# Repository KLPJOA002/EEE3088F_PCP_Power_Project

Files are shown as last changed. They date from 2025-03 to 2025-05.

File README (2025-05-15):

# Micromouse Power Subsystem – EEE3088F 2025

This repository contains the design files, documentation, and supporting material for the **Micromouse Power Subsystem** designed as part of the EEE3088F course at the University of Cape Town. The subsystem was built to meet a strict set of functional and mechanical requirements under tight budget constraints.

## 🧭 Project Overview

Micromouse is a global robotics competition in which small autonomous robots solve mazes. The UCT EEE3088F course replicates this challenge by requiring students to develop individual subsystems that together build a complete micromouse. This repository documents the design and implementation of the **Power Subsystem**, which is responsible for:

- Bidirectional control of 4 motors (2x 200mA, 2x 500mA)
- Battery charging (with selectable fast and slow charging modes)
- USB-C PD negotiation (9V)
- 5V and 3.3V regulation
- External load switching (2x 1A high-side loads)
- Ultra-low power OFF mode (<30µA)
- INA219 current and voltage monitoring

---

## 🗂 Repository Structure

---

## 🛠 Hardware Requirements

- **Battery**: 3.7V 800mAh LiPo (Micro Robotics)
- **USB PD IC**: HUSB237 for 9V negotiation
- **Motor Driver**: DRV8833 for up to 2A peak per motor
- **Load Switch**: AP22814 (3A capable, overcurrent protected)
- **Battery Monitor**: INA219 over I2C
- **Charging IC**: TP4056-42-ESOP8
- **Voltage Regulators**:
  - 5V: MT3608 Boost Converter
  - 3.3V: AMS1117-3.3 Linear Regulator

---

## ✅ Final Design Summary

- **Footprint**: 82mm × 60mm, mounted via motherboard drill holes
- **Connector**: 2×16 2.54mm header, JST-PH battery connector
- **5V and 3.3V Outputs**:
  - 5V output: up to 1.5A (±5%)
  - 3.3V output: up to 300mA (±5%)
- **Charging Modes**:
  - Slow: ~200mA (logic low on control pin)
  - Fast: ~600mA (logic high on control pin)
- **Sleep Mode**: OFF current draw <30µA, confirmed via test pads
- **INA219**: Allows shunt-based battery current measurement

---

## 🔧 How to Use

1. Open the KiCad project in `/KiCad_Files`.
2. Review schematic, footprints, and PCB constraints.
3. Upload files from `/Gerbers`, `/PnP`, and `/BOM` to JLCPCB.
4. Use `/Screenshots` for evidence of successful upload and configuration.

---

## 📦 JLCPCB Submission

All files have been validated and successfully uploaded to JLCPCB. Screenshots showing the:
- Correct **BOM upload**
- Matching **cart configuration**
are provided in `/Screenshots`.

---

## 👨‍💻 Authors

- **Alex Hillman** `HLLALE010`
- **Joab Kloppers** `KLPJOA002`
Both team members contributed distinct sections of the PCB design and documentation, as per the individual assessment requirements of the course.

- GitHub: [EEE3088F_PCP_Power_Project](https://github.com/KLPJOA002/EEE3088F_PCP_Power_Project)

> Contributions are limited to the Power Subsystem. Design files and reports are subject to UCT's academic integrity policies.

---

## 📜 License

This project is licensed for academic purposes only.

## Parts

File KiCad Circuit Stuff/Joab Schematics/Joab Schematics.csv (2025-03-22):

Source: | C:\Users\joabk\OneDrive - University of Cape Town\2025\Sem1\EEE3088F Material\MM Project\KiCad Circuit Stuff\Joab Schematics\Joab Schematics.kicad_sch
Date: | 2025/03/21 17:14:41
Tool: | Eeschema 7.0.1
Generator: | C:\Program Files\KiCad\7.0\bin\scripting\plugins/bom_csv_grouped_by_value_with_fp.py
Component Count: | 9
Ref | Qnty | Value | Cmp name | Footprint | Description | Vendor | DNP
C1, C2 | 2 | 22u | C_Small |  | Unpolarized capacitor, small symbol
D1 | 1 | SS34 | D_Schottky_Small |  | Schottky diode, small symbol
J1 | 1 | Conn_02x16_Odd_Even | Conn_02x16_Odd_Even |  | Generic connector, double row, 02x16, odd/even pin numbering scheme (row 1 odd numbers, row 2 even numbers), script generated (kicad-library-utils/schlib/autogen/connector/)
L1 | 1 | 10u | L_Small |  | Inductor, small symbol
R1 | 1 | 680k | R_Small_US |  | Resistor, small US symbol
R2 | 1 | 56k | R_Small_US |  | Resistor, small US symbol
R3 | 1 | 100k | R_Small_US |  | Resistor, small US symbol
U1 | 1 | MT3608 | MT3608 | Package_TO_SOT_SMD:SOT-23-6 | High Efficiency 1.2MHz 2A Step Up Converter, 2-24V Vin, 28V Vout, 4A current limit, 1.2MHz, SOT23-6

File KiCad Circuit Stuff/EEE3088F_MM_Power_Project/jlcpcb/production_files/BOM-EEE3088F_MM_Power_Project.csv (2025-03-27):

Comment | Designator | Footprint | LCSC | Quantity
1k | R12 | R_0402_1005Metric_Pad0.72x0.64mm_HandSolder | C11702 | 1
2.2uF | C11,C15 | C_0402_1005Metric_Pad0.74x0.62mm_HandSolder | C12530 | 2
22u | C1,C2 | C_1206_3216Metric_Pad1.33x1.80mm_HandSolder | C12891 | 2
CA45-A-10V-22UF-K | C5 | CASE-A_3216 | C129272 | 1
100p | C3 | C_0603_1608Metric_Pad1.08x0.95mm_HandSolder | C14858 | 1
10nF | C12,C16 | C_0402_1005Metric_Pad0.74x0.62mm_HandSolder | C15195 | 2
100nF | C23,C32 | C_0402_1005Metric_Pad0.74x0.62mm_HandSolder | C1525 | 2
10p | C8 | C_0603_1608Metric_Pad1.08x0.95mm_HandSolder | C1634 | 1
TP4056 | U5 | ESOP-8_L4.9-W3.9-P1.27-LS6.0-BL-EP | C16581 | 1
SS-12D06-G050 | U11 | SW-TH_3P-P4.70_SS-12D06-G050 | C17179521 | 1
220u | C10,C20,C21,C30,C31 | C_Elec_6.3x7.7 | C19100600 | 5
4.7u | C6 | C_0603_1608Metric_Pad1.08x0.95mm_HandSolder | C19666 | 1
10uF | C14,C17,C7,C9 | C_0603_1608Metric_Pad1.08x0.95mm_HandSolder | C19702 | 4
0R | R5,R6 | R_0603_1608Metric_Pad0.98x0.95mm_HandSolder | C21189 | 2
HUSB237-AA001-DN06R | U9 | TDFN-6_L2.0-W2.0-P0.65-TL-EP | C22373734 | 1
2.2R | R8 | R_0603_1608Metric_Pad0.98x0.95mm_HandSolder | C22939 | 1
220k | R2 | R_0603_1608Metric_Pad0.98x0.95mm_HandSolder | C22961 | 1
4.7R | R7 | R_0603_1608Metric_Pad0.98x0.95mm_HandSolder | C23164 | 1
75k | R15 | R_0603_1608Metric_Pad0.98x0.95mm_HandSolder | C23242 | 1
10k | R13 | R_0402_1005Metric_Pad0.72x0.64mm_HandSolder | C25744 | 1
33k | R4 | R_0402_1005Metric_Pad0.72x0.64mm_HandSolder | C25779 | 1
2.2k | R10,R11,R14 | R_0402_1005Metric_Pad0.72x0.64mm_HandSolder | C25879 | 3
3.3k | R16,R17,R9 | R_0402_1005Metric_Pad0.72x0.64mm_HandSolder | C25890 | 3
AP22814AW5-7 | U12,U14 | SOT-25_L3.0-W1.6-P0.95-LS2.8-BL | C2680321 | 2
TYPE-C_16P_QTGM027 | U7 | USB-C-SMD_TYPE-C-16P-QTGM027 | C2681552 | 1
22k | R3 | R_0603_1608Metric_Pad0.98x0.95mm_HandSolder | C31850 | 1
TS5A3159DCKR | U6 | SC-70-6_L2.0-W1.3-P0.65-LS2.1-BL-1 | C46388 | 1
DRV8833PWP | U10,U8 | TSSOP-16_L5.0-W4.4-P0.65-LS6.4-BL-EP | C50506 | 2
1uF | C13,C28,C33 | C_0402_1005Metric_Pad0.74x0.62mm_HandSolder | C52923 | 3
AMS1117-3.3 | U3 | SOT-223-3_TabPin2 | C6186 | 1
TAJA106K016RNJ | C4 | CAP-SMD_L3.2-W1.6-RD-C7171 | C7171 | 1
100m | R1 | R_1206_3216Metric_Pad1.30x1.75mm_HandSolder | C7467250 | 1
22u | L2,L3 | L_Sunlord_SWPA6045S | C83454 | 2
MT3608 | U1 | SOT-23-6 | C84817 | 1
SS34_C8678 | D1,D2 | SMA_L4.3-W2.6-LS5.2-RD | C8678 | 2
INA219AIDCNR | U2 | SOT-23-8_L3.0-W1.7-P0.65-LS2.8-BR | C87469 | 1
TPS5430DDAR | U4 | ESOP-8_L4.9-W3.9-P1.27-LS6.0-TL-EP | C9864 | 1

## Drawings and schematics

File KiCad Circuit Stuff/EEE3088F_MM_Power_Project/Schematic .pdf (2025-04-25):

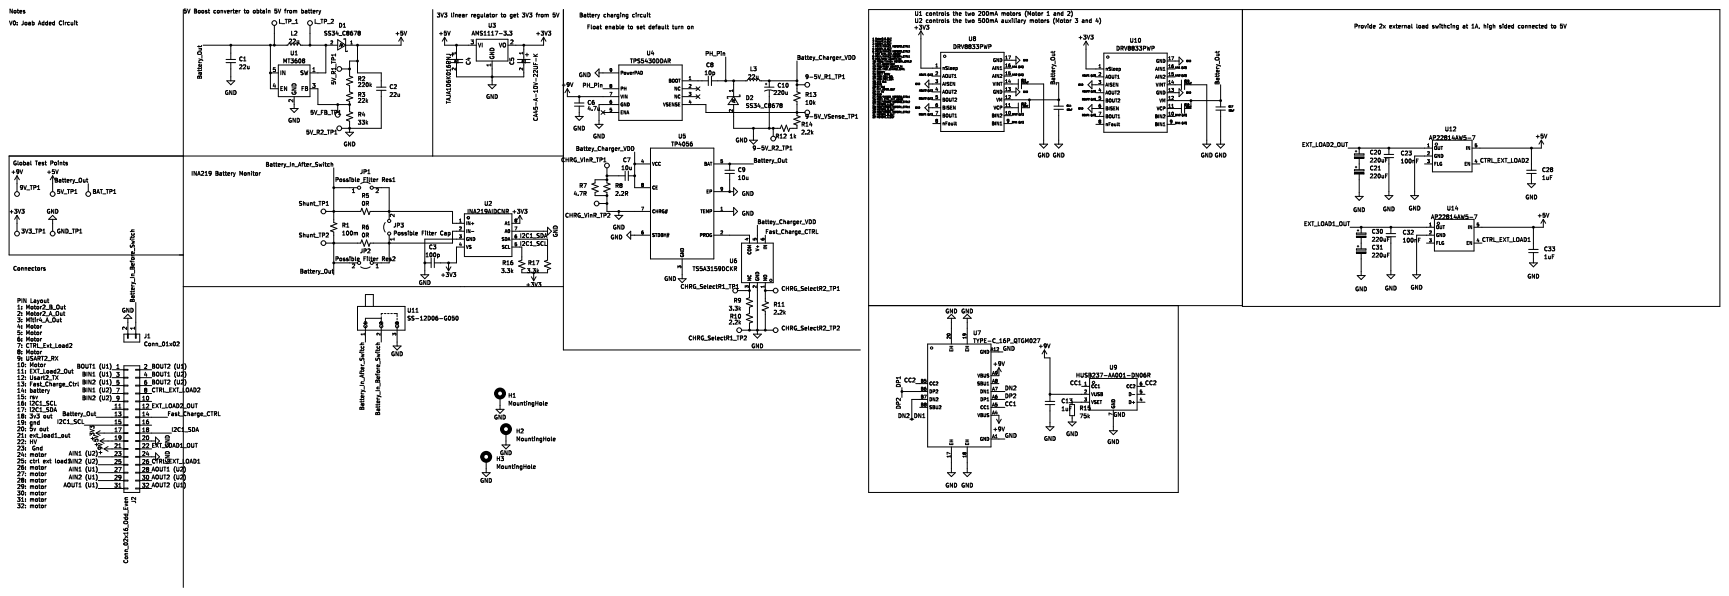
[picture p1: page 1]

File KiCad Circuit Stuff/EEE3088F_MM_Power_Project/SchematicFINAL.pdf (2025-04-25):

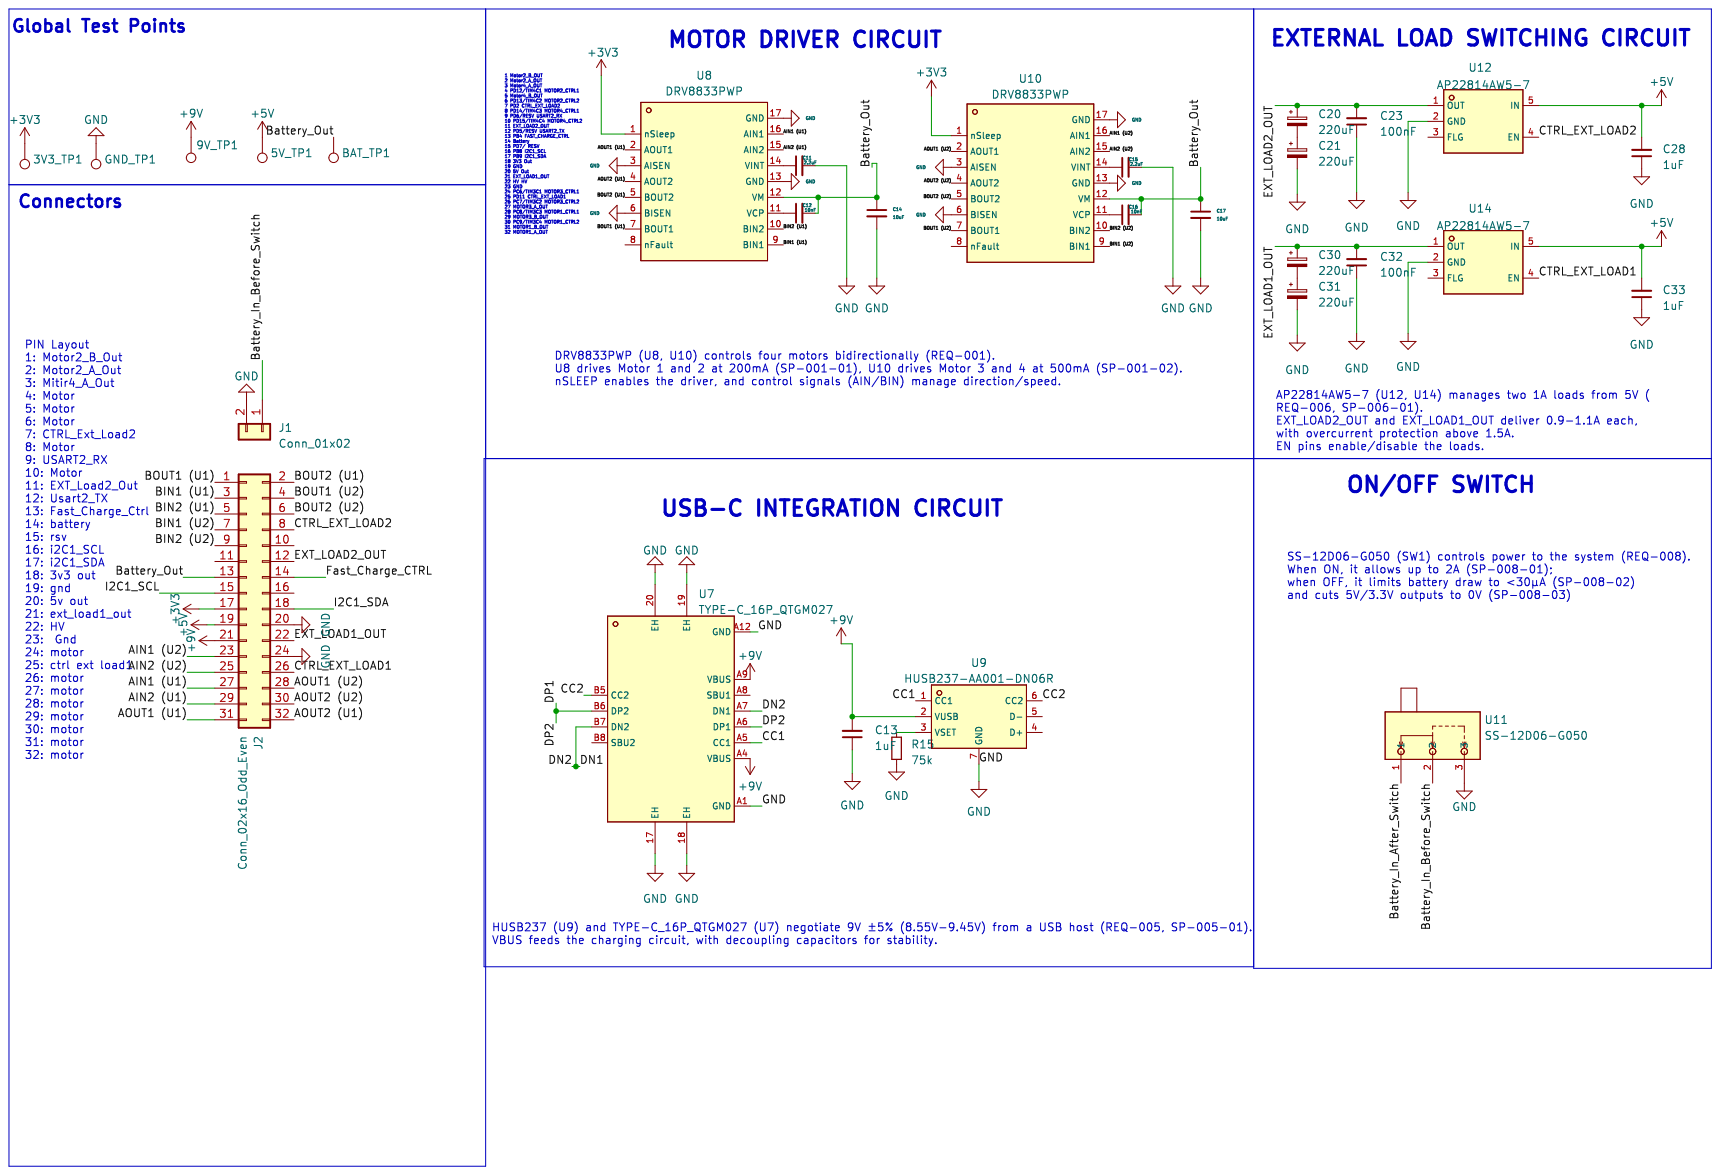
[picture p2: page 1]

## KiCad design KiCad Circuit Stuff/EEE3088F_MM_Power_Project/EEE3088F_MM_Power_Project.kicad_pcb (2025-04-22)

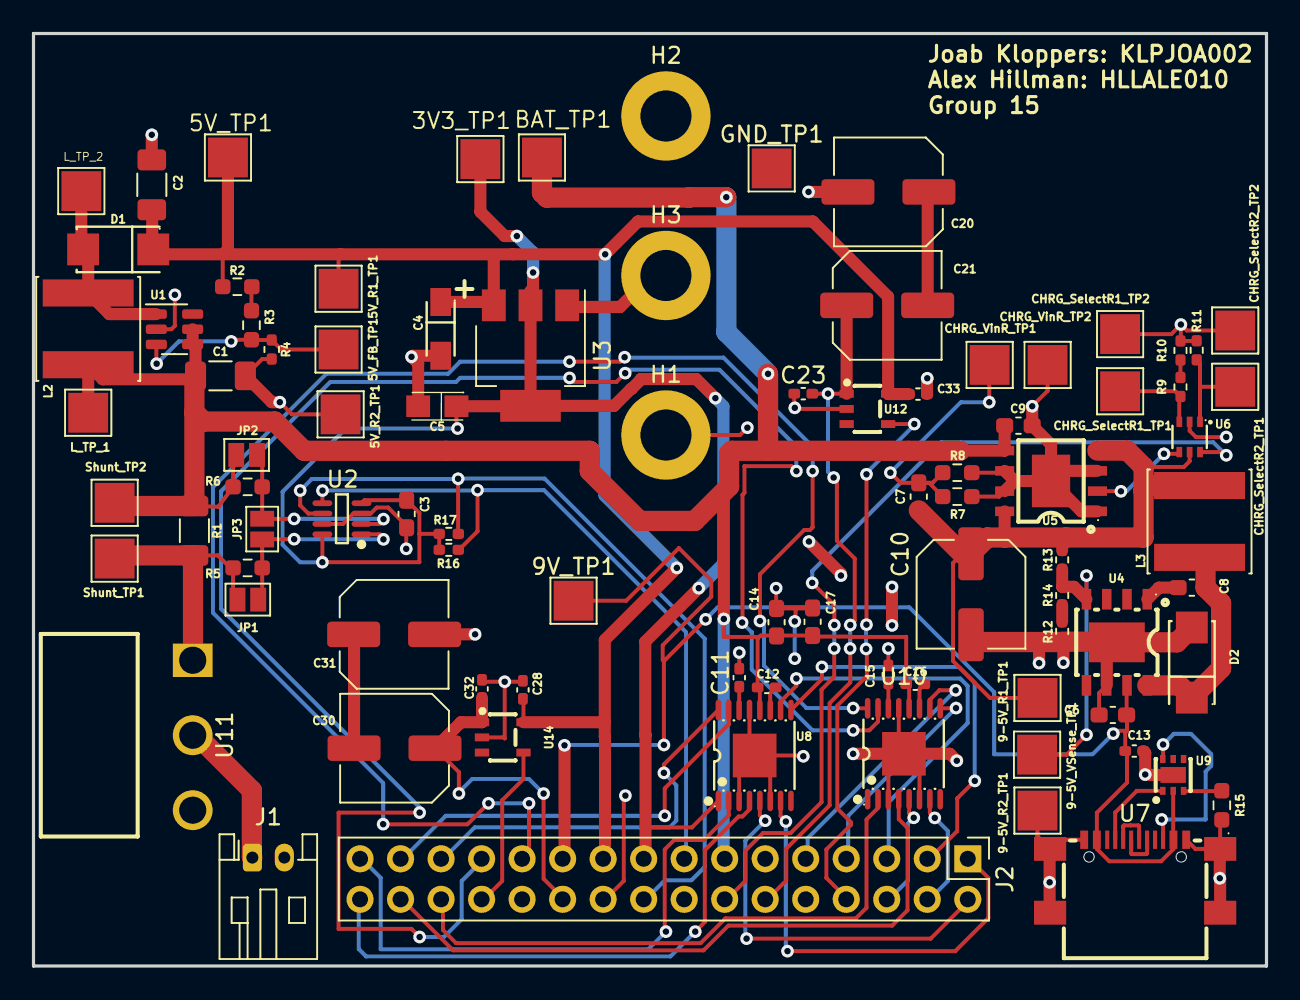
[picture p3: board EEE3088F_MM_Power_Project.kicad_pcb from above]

Board: 2 copper layers, 77.3 x 58.5 mm, 88 parts (0 on the bottom side), 56 nets.

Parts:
3V3_TP1: 3V3 TP; TestPoint_Pad_2.5x2.5mm
5V_FB_TP1: 5V FB TP; TestPoint_Pad_2.5x2.5mm
5V_R1_TP1: TestPoint_Pad_2.5x2.5mm
5V_R2_TP1: 5V R2 TP; TestPoint_Pad_2.5x2.5mm
5V_TP1: 5V TP; TestPoint_Pad_2.5x2.5mm
9-5V_R1_TP1: 9-5V R1 TP; TestPoint_Pad_2.5x2.5mm
9-5V_R2_TP1: 9-5V R2 TP; TestPoint_Pad_2.5x2.5mm
9-5V_VSense_TP1: 9-5V VSense TP; TestPoint_Pad_2.5x2.5mm
9V_TP1: 9V TP; TestPoint_Pad_2.5x2.5mm
BAT_TP1: BAT TP; TestPoint_Pad_2.5x2.5mm
C1, C2: 22u; C_1206_3216Metric_Pad1.33x1.80mm_HandSolder
C3: 100p; C_0603_1608Metric_Pad1.08x0.95mm_HandSolder
C4: TAJA106K016RNJ; CAP-SMD_L3.2-W1.6-RD-C7171
C5: CA45-A-10V-22UF-K; CASE-A_3216
C6: 4.7u; C_0603_1608Metric_Pad1.08x0.95mm_HandSolder
C7, C9: 10u; C_0603_1608Metric_Pad1.08x0.95mm_HandSolder
C8: 10p; C_0603_1608Metric_Pad1.08x0.95mm_HandSolder
C10: 220u; C_Elec_6.3x7.7
C11, C15: 2.2uF; C_0402_1005Metric_Pad0.74x0.62mm_HandSolder
C12, C16: 10nF; C_0402_1005Metric_Pad0.74x0.62mm_HandSolder
C13, C28, C33: 1uF; C_0402_1005Metric_Pad0.74x0.62mm_HandSolder
C14, C17: 10uF; C_0603_1608Metric_Pad1.08x0.95mm_HandSolder
C20, C21, C30, C31: 220uF; C_Elec_6.3x7.7
C23, C32: 100nF; C_0402_1005Metric_Pad0.74x0.62mm_HandSolder
CHRG_SelectR1_TP1, CHRG_SelectR1_TP2, CHRG_SelectR2_TP1, CHRG_SelectR2_TP2: TestPoint; TestPoint_Pad_2.5x2.5mm
CHRG_VinR_TP1, CHRG_VinR_TP2: TestPoint; TestPoint_Pad_2.5x2.5mm
D1, D2: SS34_C8678; SMA_L4.3-W2.6-LS5.2-RD
GND_TP1: GND TP; TestPoint_Pad_2.5x2.5mm
H1, H2, H3: MountingHole; MountingHole_3.2mm_M3_DIN965_Pad
J1: Conn_01x02; JST_PH_S2B-PH-K_1x02_P2.00mm_Horizontal
J2: Conn_02x16_Odd_Even; PinHeader_2x16_P2.54mm_Vertical
JP1: Possible Filter Res1; SolderJumper-2_P1.3mm_Open_Pad1.0x1.5mm
JP2: Possible Filter Res2; SolderJumper-2_P1.3mm_Open_Pad1.0x1.5mm
JP3: Possible Filter Cap; SolderJumper-2_P1.3mm_Open_Pad1.0x1.5mm
L2, L3: 22u; L_Sunlord_SWPA6045S
L_TP_1, L_TP_2: TestPoint_Pad_2.5x2.5mm
R1: 100m; R_1206_3216Metric_Pad1.30x1.75mm_HandSolder
R2: 220k; R_0603_1608Metric_Pad0.98x0.95mm_HandSolder
R3: 22k; R_0603_1608Metric_Pad0.98x0.95mm_HandSolder
R4: 33k; R_0402_1005Metric_Pad0.72x0.64mm_HandSolder
R5, R6: 0R; R_0603_1608Metric_Pad0.98x0.95mm_HandSolder
R7: 4.7R; R_0603_1608Metric_Pad0.98x0.95mm_HandSolder
R8: 2.2R; R_0603_1608Metric_Pad0.98x0.95mm_HandSolder
R9, R16, R17: 3.3k; R_0402_1005Metric_Pad0.72x0.64mm_HandSolder
R10, R11, R14: 2.2k; R_0402_1005Metric_Pad0.72x0.64mm_HandSolder
R12: 1k; R_0402_1005Metric_Pad0.72x0.64mm_HandSolder
R13: 10k; R_0402_1005Metric_Pad0.72x0.64mm_HandSolder
R15: 75k; R_0603_1608Metric_Pad0.98x0.95mm_HandSolder
Shunt_TP1, Shunt_TP2: TestPoint; TestPoint_Pad_2.5x2.5mm
U1: MT3608; SOT-23-6
U2: INA219AIDCNR; SOT-23-8_L3.0-W1.7-P0.65-LS2.8-BR
U3: AMS1117-3.3; SOT-223-3_TabPin2
U4: TPS5430DDAR; ESOP-8_L4.9-W3.9-P1.27-LS6.0-TL-EP
U5: TP4056; ESOP-8_L4.9-W3.9-P1.27-LS6.0-BL-EP
U6: TS5A3159DCKR; SC-70-6_L2.0-W1.3-P0.65-LS2.1-BL-1
U7: TYPE-C_16P_QTGM027; USB-C-SMD_TYPE-C-16P-QTGM027
U8, U10: DRV8833PWP; TSSOP-16_L5.0-W4.4-P0.65-LS6.4-BL-EP
U9: HUSB237-AA001-DN06R; TDFN-6_L2.0-W2.0-P0.65-TL-EP
U11: SS-12D06-G050; SW-TH_3P-P4.70_SS-12D06-G050
U12, U14: AP22814AW5-7; SOT-25_L3.0-W1.6-P0.95-LS2.8-BL

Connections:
+3V3: 3V3_TP1.1, C3.1, C5.1, J2.17, R16.2, R17.2, U2.4 (VS), U2.8 (A1), U3.2 (VO), U8.1 (nSleep), U10.1 (nSleep)
+5V: 5V_R1_TP1.1, 5V_TP1.1, C2.1, C4.1, C28.2, C33.2, D1.1 (K), J2.19, R2.1, U3.3 (VI), U12.5 (IN), U14.5 (IN)
+9V: 9V_TP1.1, C6.2, C13.2, J2.21, U4.7 (VIN), U7.A4 (VBUS), U7.A9 (VBUS), U9.2 (VUSB)
/AIN1 (U1): J2.27, U8.16 (AIN1)
/AIN1 (U2): J2.23, U10.16 (AIN1)
/AIN2 (U1): J2.29, U8.15 (AIN2)
/AIN2 (U2): J2.25, U10.15 (AIN2)
/AOUT1 (U1): J2.31, U8.2 (AOUT1)
/AOUT1 (U2): J2.28, U10.2 (AOUT1)
/AOUT2 (U1): J2.32, U8.4 (AOUT2)
/AOUT2 (U2): J2.30, U10.4 (AOUT2)
/BIN1 (U1): J2.3, U8.9 (BIN1)
/BIN1 (U2): J2.7, U10.9 (BIN1)
/BIN2 (U1): J2.5, U8.10 (BIN2)
/BIN2 (U2): J2.9, U10.10 (BIN2)
/BOUT1 (U1): J2.1, U8.7 (BOUT1)
/BOUT1 (U2): J2.4, U10.7 (BOUT1)
/BOUT2 (U1): J2.2, U8.5 (BOUT2)
/BOUT2 (U2): J2.6, U10.5 (BOUT2)
/Battery_In_After_Switch: JP1.1 (A), R1.2, R5.1, Shunt_TP1.1, U11.1
/Battery_In_Before_Switch: J1.1, U11.2
/Battery_Out: BAT_TP1.1, C1.1, C9.2, C12.2, C14.1, C16.2, C17.1, J2.13, JP2.2 (B), L2.1, L_TP_1.1, R1.1, R6.1, Shunt_TP2.1, U1.4 (EN), U1.5 (IN), U5.5 (BAT), U8.12 (VM), U10.12 (VM)
/Battey_Charger_VDD: 9-5V_R1_TP1.1, C7.2, C10.1, L3.2, R13.1, U5.4 (VCC), U5.8 (CE), U6.5 (V+)
/CC1: U7.A5 (CC1), U9.1 (CC1)
/CC2: U7.B5 (CC2), U9.6 (CC2)
/CTRL_EXT_LOAD1: J2.26, U14.4 (EN)
/CTRL_EXT_LOAD2: J2.8, U12.4 (EN)
/DN1: U7.A7 (DN1), U7.B7 (DN2)
/DP1: U7.A6 (DP1), U7.B6 (DP2)
/EXT_LOAD1_OUT: C30.1, C32.2, J2.22, U14.1 (OUT)
/EXT_LOAD2_OUT: C20.1, C23.2, J2.12, U12.1 (OUT)
/Fast_Charge_CTRL: J2.14, U6.6 (IN)
/I2C1_SCL: J2.15, R16.1, U2.5 (SCL)
/I2C1_SDA: J2.18, R17.1, U2.6 (SDA)
/PH_Pin: C8.2, D2.1 (K), L3.1, U4.8 (PH)
GND: 5V_R2_TP1.1, 9-5V_R2_TP1.1, C1.2, C2.2, C3.2, C4.2, C5.2, C6.1, C9.1, C10.2, C11.2, C13.1, C14.2, C15.2, C17.2, C21.2, C23.1, C28.1, C31.2, C32.1, C33.1, CHRG_SelectR1_TP2.1, CHRG_SelectR2_TP2.1, CHRG_VinR_TP2.1, D2.2 (A), GND_TP1.1, H1.1, H2.1, H3.1, J1.2, J2.20, J2.24, R4.2, R7.2, R8.2, R10.2, R11.2, R12.1, R15.2, U1.2 (GND), U2.3 (GND), U2.7 (A0), U3.1 (GND), U4.6 (GND), U4.9 (PowerPAD), U5.1 (TEMP), U5.3 (GND), U5.6 (STDBY#), U5.7 (CHRG#), U5.9 (EP), U6.2 (GND), U7.17 (EH), U7.18 (EH), U7.19 (EH), U7.20 (EH), U7.A1 (GND), U7.A12 (GND), U8.3 (AISEN), U8.6 (BISEN), U8.13 (GND), U8.17 (GND), U9.7 (GND), U10.3 (AISEN), U10.6 (BISEN), U10.13 (GND), U10.17 (GND), U11.3, U12.2 (GND), U14.2 (GND)
unnamed: C7.1, CHRG_VinR_TP1.1, R7.1, R8.1
unnamed: C20.2, C21.1
unnamed: C30.2, C31.1
unnamed: D1.2 (A), L2.2, L_TP_2.1, U1.1 (SW)
unnamed: JP1.2 (B), JP3.2 (B), R5.2, U2.1 (IN+)
unnamed: JP2.1 (A), JP3.1 (A), R6.2, U2.2 (IN-)
unnamed: R2.2, R3.1
unnamed: R9.2, R10.1
unnamed: R12.2, R14.2
unnamed: 5V_FB_TP1.1, R3.2, R4.1, U1.3 (FB)
unnamed: C8.1, U4.1 (BOOT)
unnamed: 9-5V_VSense_TP1.1, R13.2, R14.1, U4.4 (VSENSE)
unnamed: U5.2 (PROG), U6.4 (COM)
unnamed: CHRG_SelectR1_TP1.1, R9.1, U6.3 (NC)
unnamed: CHRG_SelectR2_TP1.1, R11.1, U6.1 (NO)
unnamed: C12.1, U8.11 (VCP)
unnamed: C11.1, U8.14 (VINT)
unnamed: R15.1, U9.3 (VSET)
unnamed: C16.1, U10.11 (VCP)
unnamed: C15.1, U10.14 (VINT)

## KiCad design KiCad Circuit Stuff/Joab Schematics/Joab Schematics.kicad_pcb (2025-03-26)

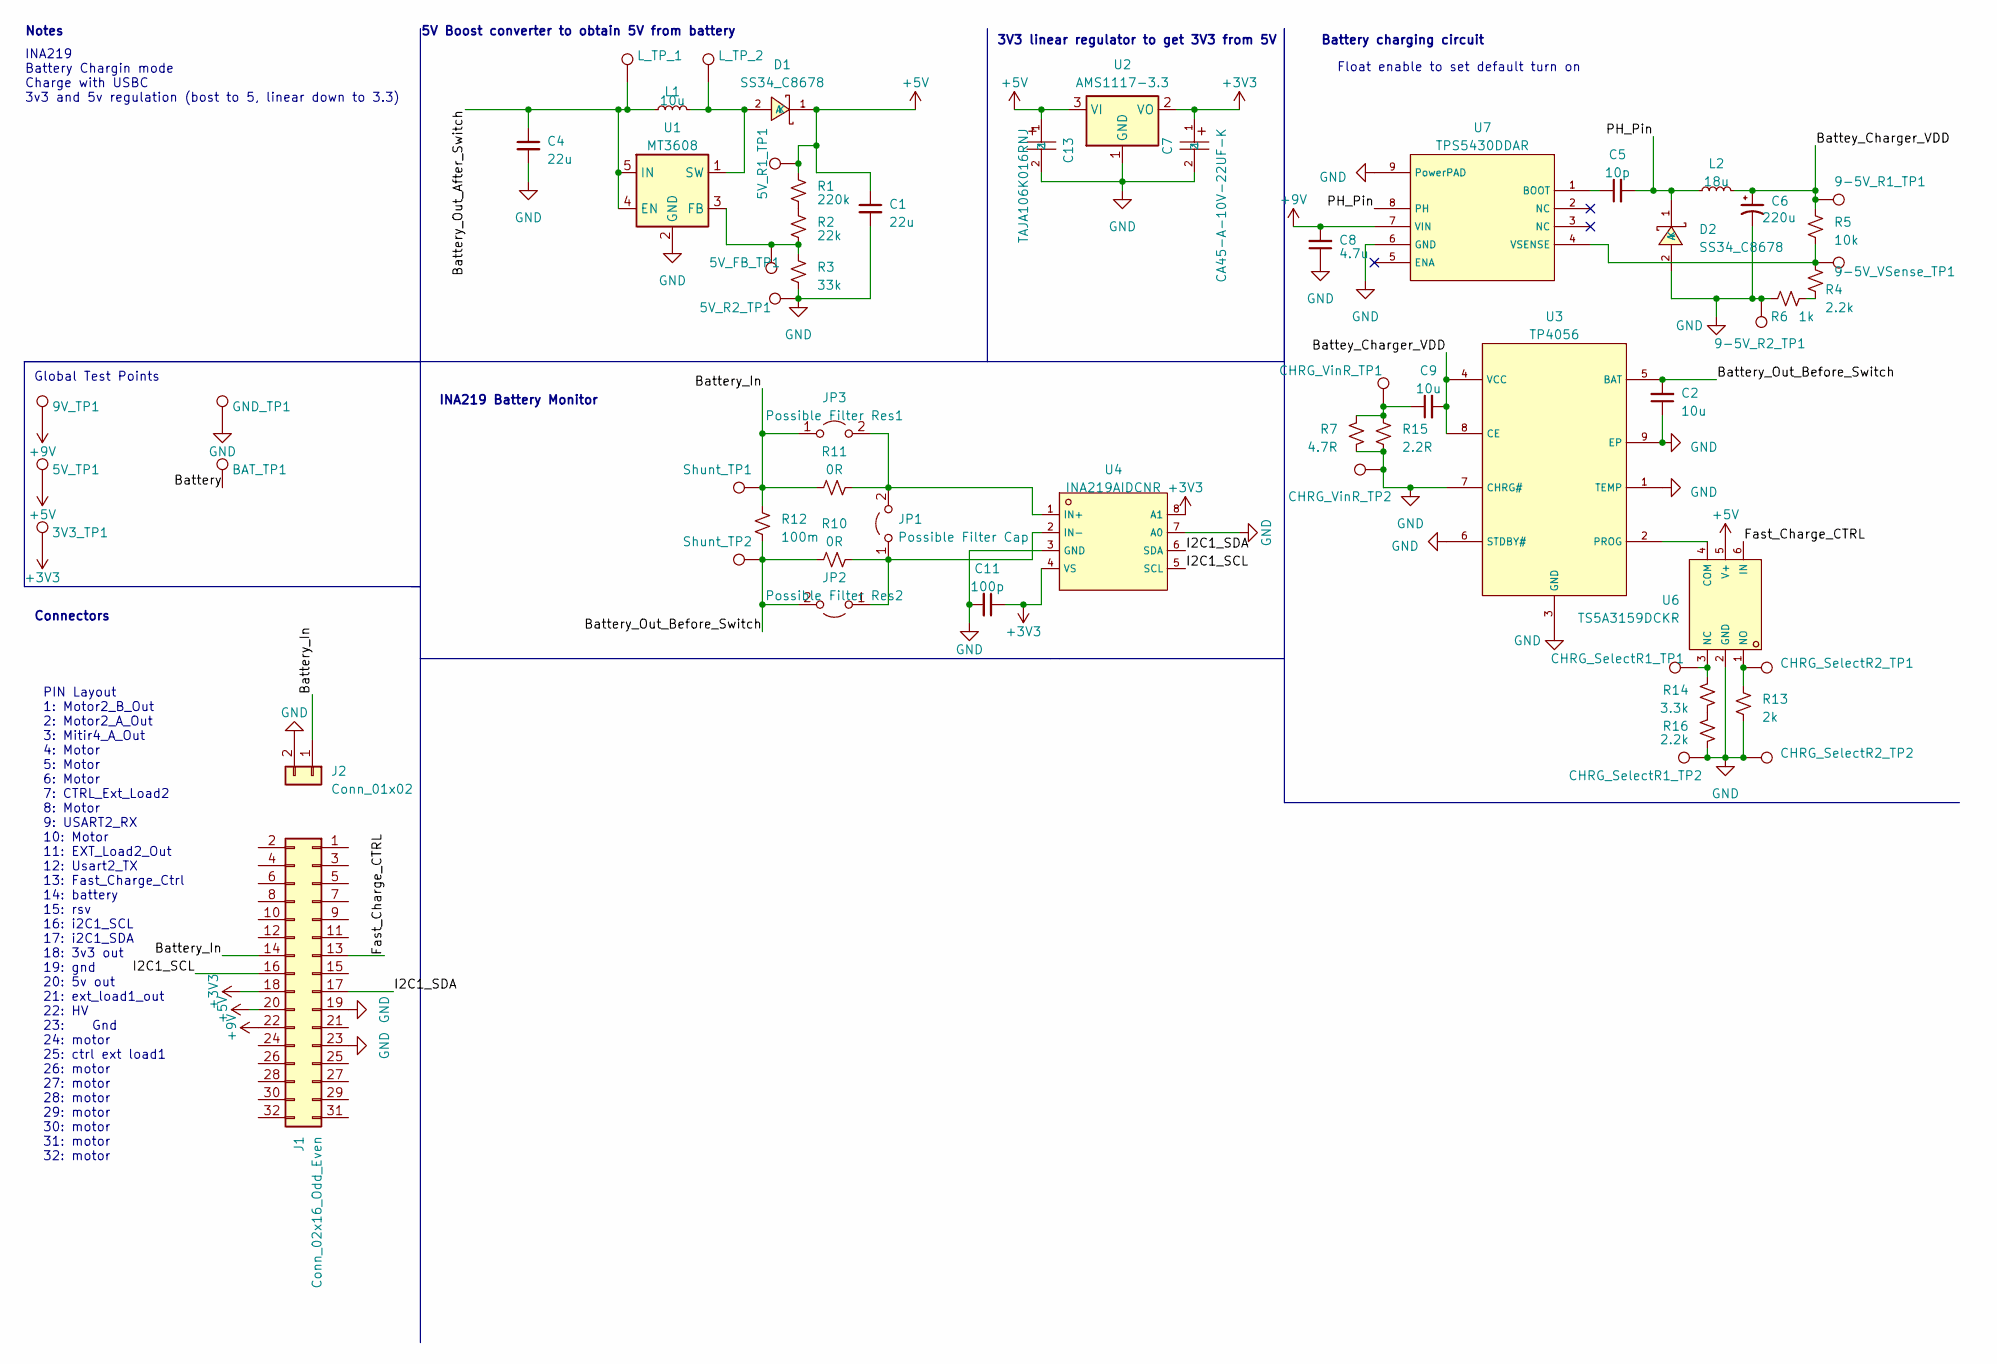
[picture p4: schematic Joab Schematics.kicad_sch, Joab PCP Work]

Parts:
3V3_TP1: 3V3 TP; TestPoint_Pad_2.5x2.5mm
5V_FB_TP1: 5V FB TP; TestPoint_Pad_2.5x2.5mm
5V_R1_TP1: TestPoint_Pad_2.5x2.5mm
5V_R2_TP1: 5V R2 TP; TestPoint_Pad_2.5x2.5mm
5V_TP1: 5V TP; TestPoint_Pad_2.5x2.5mm
9-5V_R1_TP1: 9-5V R1 TP; TestPoint_Pad_2.5x2.5mm
9-5V_R2_TP1: 9-5V R2 TP; TestPoint_Pad_2.5x2.5mm
9-5V_VSense_TP1: 9-5V VSense TP; TestPoint_Pad_2.5x2.5mm
9V_TP1: 9V TP; TestPoint_Pad_2.5x2.5mm
BAT_TP1: BAT TP; TestPoint_Pad_2.5x2.5mm
C1, C4: 22u; C_1206_3216Metric_Pad1.33x1.80mm_HandSolder; LCSC C12891
C2, C9: 10u; C_0603_1608Metric_Pad1.08x0.95mm_HandSolder; LCSC C19702
C5: 10p; C_0603_1608Metric_Pad1.08x0.95mm_HandSolder; LCSC C1634
C6: 220u; C_Elec_6.3x7.7; LCSC C19100600
C7: CA45-A-10V-22UF-K; CASE-A_3216; LCSC C129272
C8: 4.7u; C_0603_1608Metric_Pad1.08x0.95mm_HandSolder; LCSC C19666
C11: 100p; C_0603_1608Metric_Pad1.08x0.95mm_HandSolder; LCSC C14858
C13: TAJA106K016RNJ; CAP-SMD_L3.2-W1.6-RD-C7171; LCSC C7171
CHRG_SelectR1_TP1, CHRG_SelectR1_TP2, CHRG_SelectR2_TP1, CHRG_SelectR2_TP2: TestPoint; TestPoint_Pad_2.5x2.5mm
CHRG_VinR_TP1, CHRG_VinR_TP2: TestPoint; TestPoint_Pad_2.5x2.5mm
D1, D2: SS34_C8678; SMA_L4.3-W2.6-LS5.2-RD; LCSC C8678
GND_TP1: GND TP; TestPoint_Pad_2.5x2.5mm
J1: Conn_02x16_Odd_Even; PinHeader_2x16_P2.54mm_Vertical
J2: Conn_01x02; JST_PH_B2B-PH-K_1x02_P2.00mm_Vertical
JP1: Possible Filter Cap; SolderJumper-2_P1.3mm_Open_Pad1.0x1.5mm
JP2: Possible Filter Res2; SolderJumper-2_P1.3mm_Open_Pad1.0x1.5mm
JP3: Possible Filter Res1; SolderJumper-2_P1.3mm_Open_Pad1.0x1.5mm
L1: 10u; L_Changjiang_FNR4030S; LCSC C167879
L2: 18u; L_Changjiang_FNR4030S; LCSC C167882
L_TP_1, L_TP_2: TestPoint_Pad_2.5x2.5mm
R1: 220k; R_0603_1608Metric_Pad0.98x0.95mm_HandSolder; LCSC C22961
R2: 22k; R_0603_1608Metric_Pad0.98x0.95mm_HandSolder; LCSC C31850
R3: 33k; R_0402_1005Metric_Pad0.72x0.64mm_HandSolder; LCSC C25779
R4, R16: 2.2k; R_0402_1005Metric_Pad0.72x0.64mm_HandSolder; LCSC C25879
R5: 10k; R_0402_1005Metric_Pad0.72x0.64mm_HandSolder; LCSC C25744
R6: 1k; R_0402_1005Metric_Pad0.72x0.64mm_HandSolder; LCSC C11702
R7: 4.7R; R_0603_1608Metric_Pad0.98x0.95mm_HandSolder; LCSC C23164
R10, R11: 0R; R_0603_1608Metric_Pad0.98x0.95mm_HandSolder; LCSC C21189
R12: 100m; R_0402_1005Metric_Pad0.72x0.64mm_HandSolder; LCSC C7467250
R13: 2k; R_0402_1005Metric_Pad0.72x0.64mm_HandSolder; LCSC C4109
R14: 3.3k; R_0402_1005Metric_Pad0.72x0.64mm_HandSolder; LCSC C25890
R15: 2.2R; R_0603_1608Metric_Pad0.98x0.95mm_HandSolder; LCSC C22939
Shunt_TP1, Shunt_TP2: TestPoint; TestPoint_Pad_2.5x2.5mm
U1: MT3608; SOT-23-6; LCSC C84817
U2: AMS1117-3.3; SOT-223-3_TabPin2; LCSC C6186
U3: TP4056; ESOP-8_L4.9-W3.9-P1.27-LS6.0-BL-EP; LCSC C16581
U4: INA219AIDCNR; SOT-23-8_L3.0-W1.7-P0.65-LS2.8-BR; LCSC C87469
U6: TS5A3159DCKR; SC-70-6_L2.0-W1.3-P0.65-LS2.1-BL-1; LCSC C46388
U7: TPS5430DDAR; ESOP-8_L4.9-W3.9-P1.27-LS6.0-TL-EP; LCSC C9864

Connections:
+3V3: 3V3_TP1.1, C7.1, C11.1, J1.18, U2.2 (VO), U4.4 (VS), U4.8 (A1)
+5V: 5V_R1_TP1.1, 5V_TP1.1, C1.1, C13.1, D1.1 (K), J1.20, R1.1, U2.3 (VI), U6.5 (V+)
+9V: 9V_TP1.1, C8.2, J1.22, U7.7 (VIN)
/Battery: BAT_TP1.1
/Battery_In: J1.14, J2.1, JP3.1 (A), R11.1, R12.2, Shunt_TP1.1
/Battery_Out_After_Switch: C4.1, L1.1, L_TP_1.1, U1.4 (EN), U1.5 (IN)
/Battery_Out_Before_Switch: C2.2, JP2.2 (B), R10.1, R12.1, Shunt_TP2.1, U3.5 (BAT)
/Battey_Charger_VDD: 9-5V_R1_TP1.1, C6.1, C9.2, L2.2, R5.1, U3.4 (VCC), U3.8 (CE)
/Fast_Charge_CTRL: J1.13, U6.6 (IN)
/I2C1_SCL: J1.16, U4.5 (SCL)
/I2C1_SDA: J1.17, U4.6 (SDA)
/PH_Pin: C5.2, D2.1 (K), L2.1, U7.8 (PH)
GND: 5V_R2_TP1.1, 9-5V_R2_TP1.1, C1.2, C2.1, C4.2, C6.2, C7.2, C8.1, C11.2, C13.2, CHRG_SelectR1_TP2.1, CHRG_SelectR2_TP2.1, CHRG_VinR_TP2.1, D2.2 (A), GND_TP1.1, J1.19, J1.23, J2.2, R3.2, R6.1, R7.2, R13.2, R15.2, R16.2, U1.2 (GND), U2.1 (GND), U3.1 (TEMP), U3.3 (GND), U3.6 (STDBY#), U3.7 (CHRG#), U3.9 (EP), U4.3 (GND), U4.7 (A0), U6.2 (GND), U7.6 (GND), U7.9 (PowerPAD)
unnamed: C9.1, CHRG_VinR_TP1.1, R7.1, R15.1
unnamed: D1.2 (A), L1.2, L_TP_2.1, U1.1 (SW)
unnamed: JP1.1 (A), JP2.1 (A), R10.2, U4.2 (IN-)
unnamed: JP1.2 (B), JP3.2 (B), R11.2, U4.1 (IN+)
unnamed: R1.2, R2.1
unnamed: R4.2, R6.2
unnamed: R14.2, R16.1
unnamed: 5V_FB_TP1.1, R2.2, R3.1, U1.3 (FB)
unnamed: U3.2 (PROG), U6.4 (COM)
unnamed: CHRG_SelectR1_TP1.1, R14.1, U6.3 (NC)
unnamed: CHRG_SelectR2_TP1.1, R13.1, U6.1 (NO)
unnamed: C5.1, U7.1 (BOOT)
unnamed: 9-5V_VSense_TP1.1, R4.1, R5.2, U7.4 (VSENSE)

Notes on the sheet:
INA219 Battery Chargin mode Charge with USBC 3v3 and 5v regulation (bost to 5, linear down to 3.3)
PIN Layout 1: Motor2_B_Out 2: Motor2_A_Out 3: Mitir4_A_Out 4: Motor 5: Motor 6: Motor 7: CTRL_Ext_Load2 8: Motor 9: USART2_RX 10: Motor 11: EXT_Load2_Out 12: Usart2_TX 13: Fast_Charge_Ctrl 14: battery 15: rsv 16: i2C1_SCL 17: i2C1_SDA 18: 3v3 out 19: gnd 20: 5v out 21: ext_load1_out 22: HV 23: Gnd 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
Global Test Points
Float enable to set default turn on
Notes
5V Boost converter to obtain 5V from battery
3V3 linear regulator to get 3V3 from 5V
Battery charging circuit
Connectors
INA219 Battery Monitor

Board: 2 copper layers, 60 parts (0 on the bottom side), 25 nets, no tracks yet.

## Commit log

2025-03-12 Added Kicad Files
    [EEE3088F_MM_Power_Project.kicad_pcb, EEE3088F_MM_Power_Project.kicad_sch]
2025-03-12 added comment
    [EEE3088F_MM_Power_Project.kicad_sch]
2025-03-12 Added two new schematics for each person to work independantly
    [Alex Schematics.kicad_pcb, Alex Schematics.kicad_sch, Joab Schematics.kicad_pcb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]
2025-03-20 Added some things
    [Joab Schematics.kicad_sch]
2025-03-20 I added a driver IC
    [Alex Schematics.kicad_sch]
2025-03-20 Did some voltage Regulation for 5v without calculating values
    [Joab Schematics.kicad_sch]
2025-03-22 Added 5V and 3v3 Regulation, started on battery charging
    [Joab Schematics.csv, Joab Schematics.kicad_sch]
2025-03-23 DId battery charger, some labeling and components
    [Joab Schematics.kicad_pcb, Joab Schematics.kicad_sch]
2025-03-23 Added INA219 monitor (kinda) and added some fixes
    [Joab Schematics.kicad_pcb, Joab Schematics.kicad_sch]
2025-03-24 Chaned Charrging IC, Chaned INA219 IC, Changed some other things
    [Joab Schematics.kicad_pcb, Joab Schematics.kicad_sch]
2025-03-24 Added Switching for charger
    [Joab Schematics.kicad_pcb, Joab Schematics.kicad_sch]
2025-03-25 added some stuff
    [Alex Schematics.kicad_pcb, Alex Schematics.kicad_sch]
2025-03-25 Changed some values of resistors, caps and inductors, Also modified some components Still need to finish adding resistors from jlcpcb
    [Joab Schematics.kicad_pcb, Joab Schematics.kicad_sch]
2025-03-26 Chose all passive components, added test points to all
    [Joab Schematics.kicad_pcb, Joab Schematics.kicad_sch]
2025-03-26 Joab Started Work on main pcb
    [EEE3088F_MM_Power_Project.kicad_pcb, EEE3088F_MM_Power_Project.kicad_sch]
2025-03-26 Connected All circuits, Ready for pcb design
    [EEE3088F_MM_Power_Project.kicad_pcb, EEE3088F_MM_Power_Project.kicad_sch]
2025-03-26 Got rid of old switch
    [EEE3088F_MM_Power_Project.kicad_pcb]
2025-03-26 Added something
    [EEE3088F_MM_Power_Project.kicad_pcb]
2025-03-26 Done Significant circuit work
    [EEE3088F_MM_Power_Project.kicad_pcb, EEE3088F_MM_Power_Project.kicad_sch]
2025-03-27 Did somke more pcb
    [EEE3088F_MM_Power_Project.kicad_pcb]
2025-03-27 Removed D+ and D- to float on the USPD
    [BOM-EEE3088F_MM_Power_Project.csv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]
2025-03-27 Changed inductors and rewired
    [EEE3088F_MM_Power_Project.kicad_pcb, EEE3088F_MM_Power_Project.kicad_sch]
2025-03-27 Added most of all connections and holes
    [EEE3088F_MM_Power_Project.kicad_pcb, EEE3088F_MM_Power_Project.kicad_sch]
2025-03-27 finished wiring
    [BOM-EEE3088F_MM_Power_Project.csv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]
2025-03-27 Made some final tweaks, and created gerber files
    [EEE3088F_MM_Power_Project-B_Cu.gbr, EEE3088F_MM_Power_Project-B_Mask.gbr, EEE3088F_MM_Power_Project-B_Silkscreen.gbr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]
2025-03-27 added stuff
    [BOM-EEE3088F_MM_Power_Project.csv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]
2025-03-27 Gerbers added
    [EEE3088F_MM_Power_Project-B_Cu.gbr, EEE3088F_MM_Power_Project-B_Mask.gbr, EEE3088F_MM_Power_Project-B_Silkscreen.gbr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]
2025-03-27 Changed JST
    [EEE3088F_MM_Power_Project-B_Cu.gbr, EEE3088F_MM_Power_Project-B_Mask.gbr, EEE3088F_MM_Power_Project-B_Silkscreen.gbr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]
2025-03-27 added final bom
    [BOM-EEE3088F_MM_Power_Project.csv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]
2025-03-27 added bom again
    [EEE3088F_MM_Power_Project-CuBottom.gbr, EEE3088F_MM_Power_Project-CuTop.gbr, EEE3088F_MM_Power_Project-EdgeCuts.gbr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]
2025-03-28 Tweaked some stuff
    [EEE3088F_MM_Power_Project-B_Cu.gbr, EEE3088F_MM_Power_Project-B_Mask.gbr, EEE3088F_MM_Power_Project-B_Silkscreen.gbr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]
2025-03-28 redid bom
    [CPL-EEE3088F_MM_Power_Project.csv, EEE3088F_MM_Power_Project-CuBottom.gbr, EEE3088F_MM_Power_Project-CuTop.gbr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]
2025-03-28 Change silkscreen and drill hole issues
    [EEE3088F_MM_Power_Project-B_Cu.gbr, EEE3088F_MM_Power_Project-B_Mask.gbr, EEE3088F_MM_Power_Project-B_Silkscreen.gbr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]
2025-03-28 added new bom
    [CPL-EEE3088F_MM_Power_Project.csv, EEE3088F_MM_Power_Project-CuBottom.gbr, EEE3088F_MM_Power_Project-CuTop.gbr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]
2025-04-22 Added some lables in Joab Schematic
    [EEE3088F_MM_Power_Project.kicad_pcb, Joab Schematics.kicad_sch]
2025-04-24 changed some stuff
    [copy.kicad_sch]
2025-04-25 Added ReadMe and other minor changes
    [EEE3088F_MM_Power_Project.kicad_sch, Joab Schematics.kicad_sch]
